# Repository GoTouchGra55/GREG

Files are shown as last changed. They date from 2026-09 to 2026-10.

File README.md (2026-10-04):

# GREG

GREG is a custom SBC designed to act as the main computer for a rover. It is built around the Allwinner T527 SoC and includes custom memory, power management, connectivity, camera, display, sensor, and motor-control hardware.

CAD REPO - [REPO](https://github.com/unknowngamer69/Orion-Rover)

## Hardware

- SoC: Allwinner T527
- RAM: 2 GB Samsung LPDDR4
- PMIC: AXP717-family
- Storage: MicroSD
- Networking: Ethernet
- Connectivity: 2× USB-A + 1× USB-C
- Display: HDMI + 5" LCD interface
- Cameras: 3-camera support (2 with multiplexing)
- Sensors: 6× ToF + LiDAR
- Debug: UART/debug connector
- Expansion: External breakout connector

## Motor Driver

Motor control is handled by a separate PCB instead of the T527.

- MCU: STM32G4
- Motor drivers: 3× DRV8262
- Motors: 6× brushed DC motors with built-in encoders

Separating the motor controller from the SBC keeps the main PCB free from clutter and noise.

## Schematics

SBC - [SEE SCHEMATICS](<Schematics(PDF)/GREG.pdf>)  
Motor Driver - [SEE SCHEMATICS](<Schematics(PDF)/GREG-MTRDRV.pdf>)

## Routing

### Motor Driver

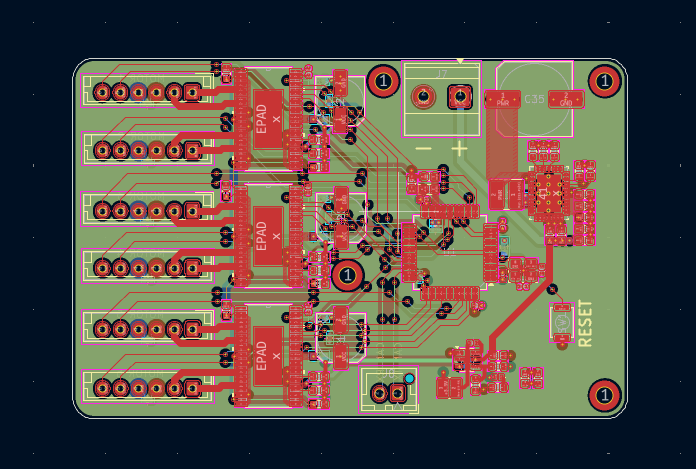
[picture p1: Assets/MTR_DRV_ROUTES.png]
Driver Routes

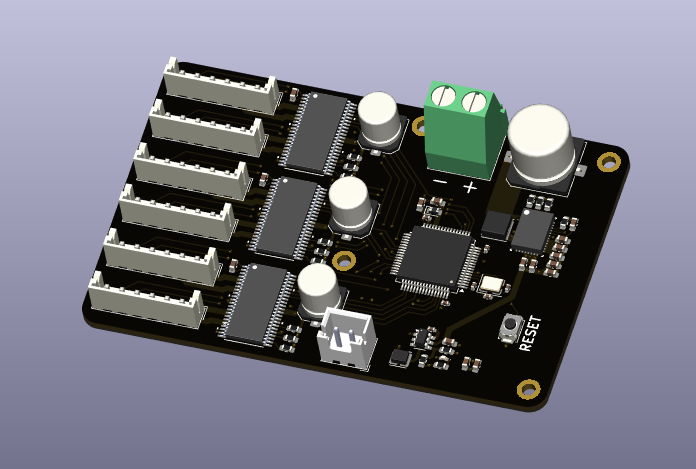
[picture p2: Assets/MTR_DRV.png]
Driver


### SBC (incomplete)

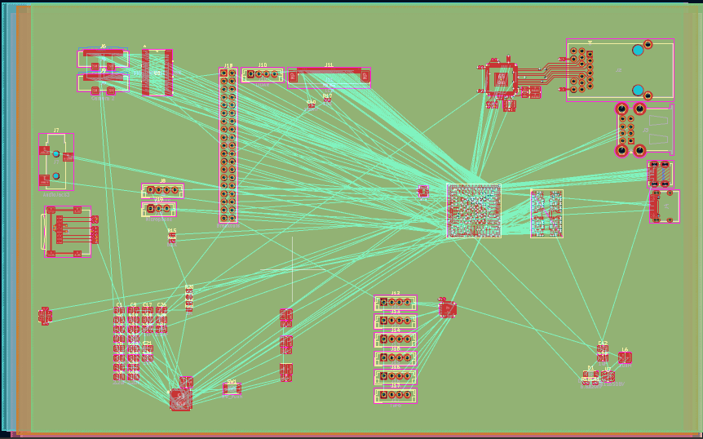
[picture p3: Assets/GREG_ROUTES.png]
GREG SBC


## Authors

Shaurya (Electronics) - [@GoTouchGra55](https://github.com/GoTouchGra55)  
Krish (CAD) - [@unknowngamer69](https://github.com/unknowngamer69)

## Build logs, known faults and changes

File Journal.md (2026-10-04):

# Week 1

## DAY 1

Today, I spent the entire time researching and configuring components on kicad. I did the research part off camera. I was initially planning to use the Rockchip RK3566 processor but it was lacking a proper datasheet so transitioned over to a more open Allwinner T527 processor. This thing has a great documentation and its cheap too!

For the RAM, I was honestly so confused between so many different choices. With the ongoing rammagedon, I though the prices would be crazy but I was shocked on seeing a 16Gb chip for as low as $49 on lcsc. It's cheap, right?

Notice anything? I wrote 16"Gb" and not "GB". This was the entire source of my confusion. Turns out 16Gb is actually just 2GB of ram. So yeah $49 definitely pretty expensive for 2GB of ram ;-;

I decided to go with the SAMSUNG K4F6E3S4HM-THCL. Its a pretty popular chip for embedded systems. Then, started wiring the DDR4 ram. I thought it would be hard af but wiring it up was just connecting similarly named pins from the CPU and on the RAM chip. With that, I finished the task!

https://lapse.hackclub.com/timelapse/3uVjpeV-KdUG

## DAY 2

Today was spent on more wiring. But I wired up the power management ic (PMIC) today. Turns out every different cpu has a whole different PMIC! I thought of using the same PMIC as used in the rk3566 but turns out it was incompatible. So, the compatible chip for the Allwinner T527 processor is the AXP717 PMIC.

Then I wired the PMIC according to the datasheet application. Its still a bit confusing but I think chatgpt or claude and elaborate it for me, if I'm unable to comprehend the datasheet contents. I also wired up power for the processor. It had a lot of different voltage requirements but i guess that's what the PMIC is supposed to be used for instead a billion different voltage regulators.

https://lapse.hackclub.com/timelapse/Uc_4LHCtApbX

## Day 3

Today I added wired connectivity to the board. I added stuff like 1 ethernet, 2 usb-a ports, 1 usb-c port, 2 camera connectors, 1 debug terminal, and 1 hdmi output port. The one that was the most confusing here are the camera connectors. We originally planned for 2 cameras (3 now) and I thought that there were enough pins on the cpu for it, but even using the MIPI DSI from the datasheet, there aren't enough pins for 2 cams. So, I'll need to figure something else out tomorrow for 3 cams.

I literally had to change the camera connector pinout 3 times bc for the first time, I thought we were going for a raspberry pi style camera so I copied that pinout. That was wrong. We changed the camera and I didn't look for the specifics of the camera we'd use. So, I thought copying a standard MIPI camera pinout was a good idea. Not a good idea again. The camera my teammate chose was the most niche camera I've ever seen. Then, I copied the final pinout for that specific camera.

Finally, I also added the micro-sd card memory section. Idk why but I went with stacked USB-A ports like a raspberry pi. Probably because it saves space. I forgot what I was thinking then.

https://lapse.hackclub.com/timelapse/OWU4e0SMXuE3

## Day 4

Today I cleaned up the camera config. Yesterday, I had cheated a bit by only making one camera functional and the other pretty much disabled. So, I added a multiplexer so that I could switch electronically between the two cameras. This was very simple to add as all the pins were pretty much self-explanatory on the MUX.

Then, I added the connectors for all extra devices to be used with the rover. I added connectors for a LiDAR, a 5" LCD display, 6x ToF sensors, and a breakout. For the 5" lcd, I had to use a separate regulator for the backlights and I also had to use another multiplexer for the ToF sensors as using up that many I2C pins would be painful to route and redundant. After that, I cleaned everything up and fixed any erros that I had made.

Finally, I've finished the schemati- SHIT. I forgot the motor driver section. Tomorrow, I'll work on the motor drivers then.

https://lapse.hackclub.com/timelapse/n_8mE_Owrke_

## Day 5

Today, I've planned to make the schematic for the motor driver. Hopefully this doesn't take too long. So, I started off with cubemx. I had to use an stm32g4 series mcu because, I really didn't want this driver to be on the SBC. That would make the sbc way too cluttered and also noisy. So, I setup some pins and timers in cubemx. It was around this time that something crashed on the system and the recording was stopped. So, I just have a random 10min lapse.

https://lapse.hackclub.com/timelapse/YH5z8TwuD9Iz

Then, I opened up kicad and set up the mcu with decoupling capacitors, reset circuitry, crystal, etc. After that, I added a drv8262 motor driver. I used this because it supported two motors instead of just one. That would mean I'd have to use only 3 of these for the 6 planned motors. The first symbol I imported for the driver was very confusing to me, so i replaced it with a "better" version.

Even after that, it took me a lot of time to figure out the pinouts. The board had multiple pins with the same name. I figured out that it was to accomodate for the huge current requirements for the motors. Also, the driver had a different pinout for single and dual motor modes. I had added some incorrect configs in cubemx, so retraced my steps and reconfigured the project. Next, it was pretty much smooth sailing. I added the power circuitry from an old project as it had a pretty similar power i/o requirement. I eventually added the CAN to both the stm32 and the t527.

Then, I changed the 2x18 pin connector to a 2x19 pin version to include the two CAN pins. Finally, I assigned the footprints to both the driver and the driver. I realized that a couple of the footprints were missing models, so i manually assigned models to those. With that, I concluded the schematics for the SBC + Motor Driver. I'll be routing the pcbs in the following week!

https://lapse.hackclub.com/timelapse/VLZOeNz0L1pe

# Week 2

# Day 1

Firstly, I added M2 mounting holes and also fixed some footprint issues for the motor driver. After that, I did some decoupling capacitor placement for the mcu. I also routed the localized sections together and used copper pours for the parts expecting high currents. That's basically all of what I've done today.

https://lapse.hackclub.com/timelapse/X0dPpF9x8SwO

# Day 2

Today, I planned out the placements for the motor drivers. It was tedious due to the oddly long nature of the motor connectors. I put them vertically on each other as horizontal would take too much space. This looks pretty good tbh. After that, I placed remaining motor driver components like the decoupling caps, resistors, bulk capacitor, etc. Then, I connected some of the localized components together with the whole board.

https://lapse.hackclub.com/timelapse/TpOebbLc9Wzu

# Day 3

Today, I connected the motor drivers to the mcu itself. Previously, it was only routed locally. After that, I cleaned up some of the older routes. I also figured out that I had accidentally mixed up the internal power supply to the external through a silly error. So, I fixed that and also fixed the corresponding routes.

https://lapse.hackclub.com/timelapse/athXvKkx-Ld6

# Day 4

Today, I connected the motor encoders to the mcu. This also resulted in some revised routes. After that, I had to resolving some plane issues. Then, I moved over a few sections to make the board more compact as it was just way too big and scattered. The motor driver is now complete.

https://lapse.hackclub.com/timelapse/TlkEq0aHov0p

# Day 5

Today, I started work on routing the sbc itself. This was very confusing as I've never worked with an sbc before. I tried to use vias but they didnt really want to work. So, I found out that I was supposed to use micro vias. I also tried to connect long distance traces together but later changed my mind as I don't think that it's a good idea. I'd rather keep the traces short and tidy instead of long and weird. Then, I followed a similar concept in the ram. I only routed together the grouped components. Gonna do more work tomorrow.

https://lapse.hackclub.com/timelapse/h11k2Ic1V0Ab

# Day 6

Today, I wired up some local routes in the sbc. I wanted to start with the RAM but as a beginner to custom sbc designs, shits pretty intimidating yk. So, I routed the ethernet section first. Then, I routed up some crystals and finally the SD card memory section. I wanted to keep the labels at first so I spent some time "prettyfying" the component placements, but then later changed my mind as it took too fricking long to do and imo just looked trash.

https://lapse.hackclub.com/timelapse/Ca1tS8nBZieB

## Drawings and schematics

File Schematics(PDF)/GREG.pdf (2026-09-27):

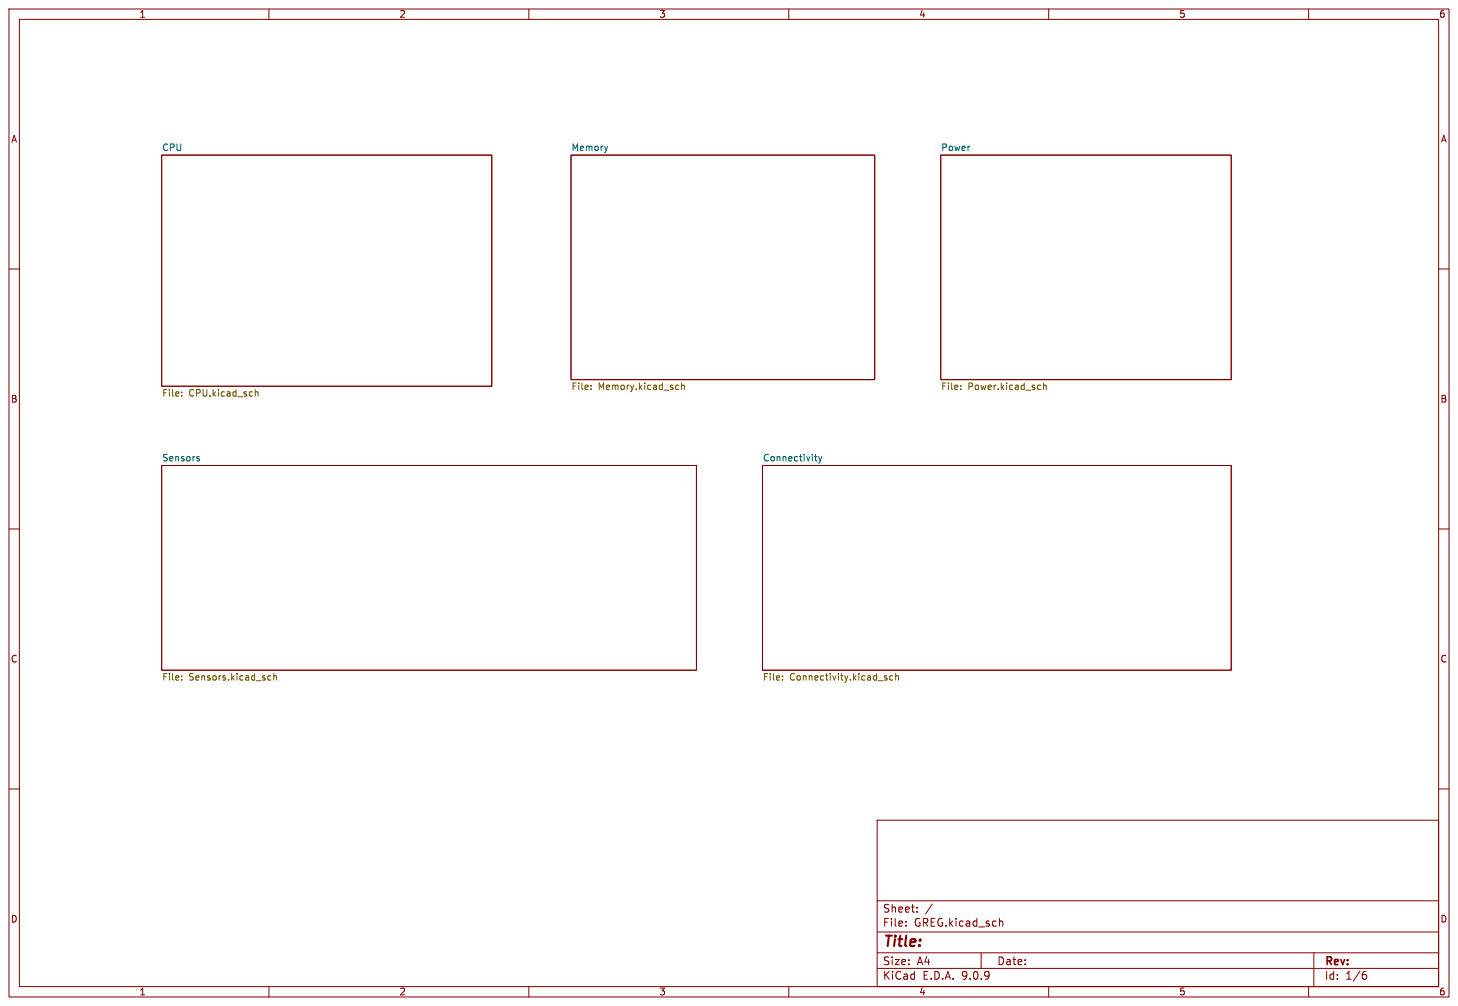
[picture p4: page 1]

Memory File: Memory.kicad_sch CPU

Id: 1/6 Title: File: GREG.kicad_sch Sheet: /

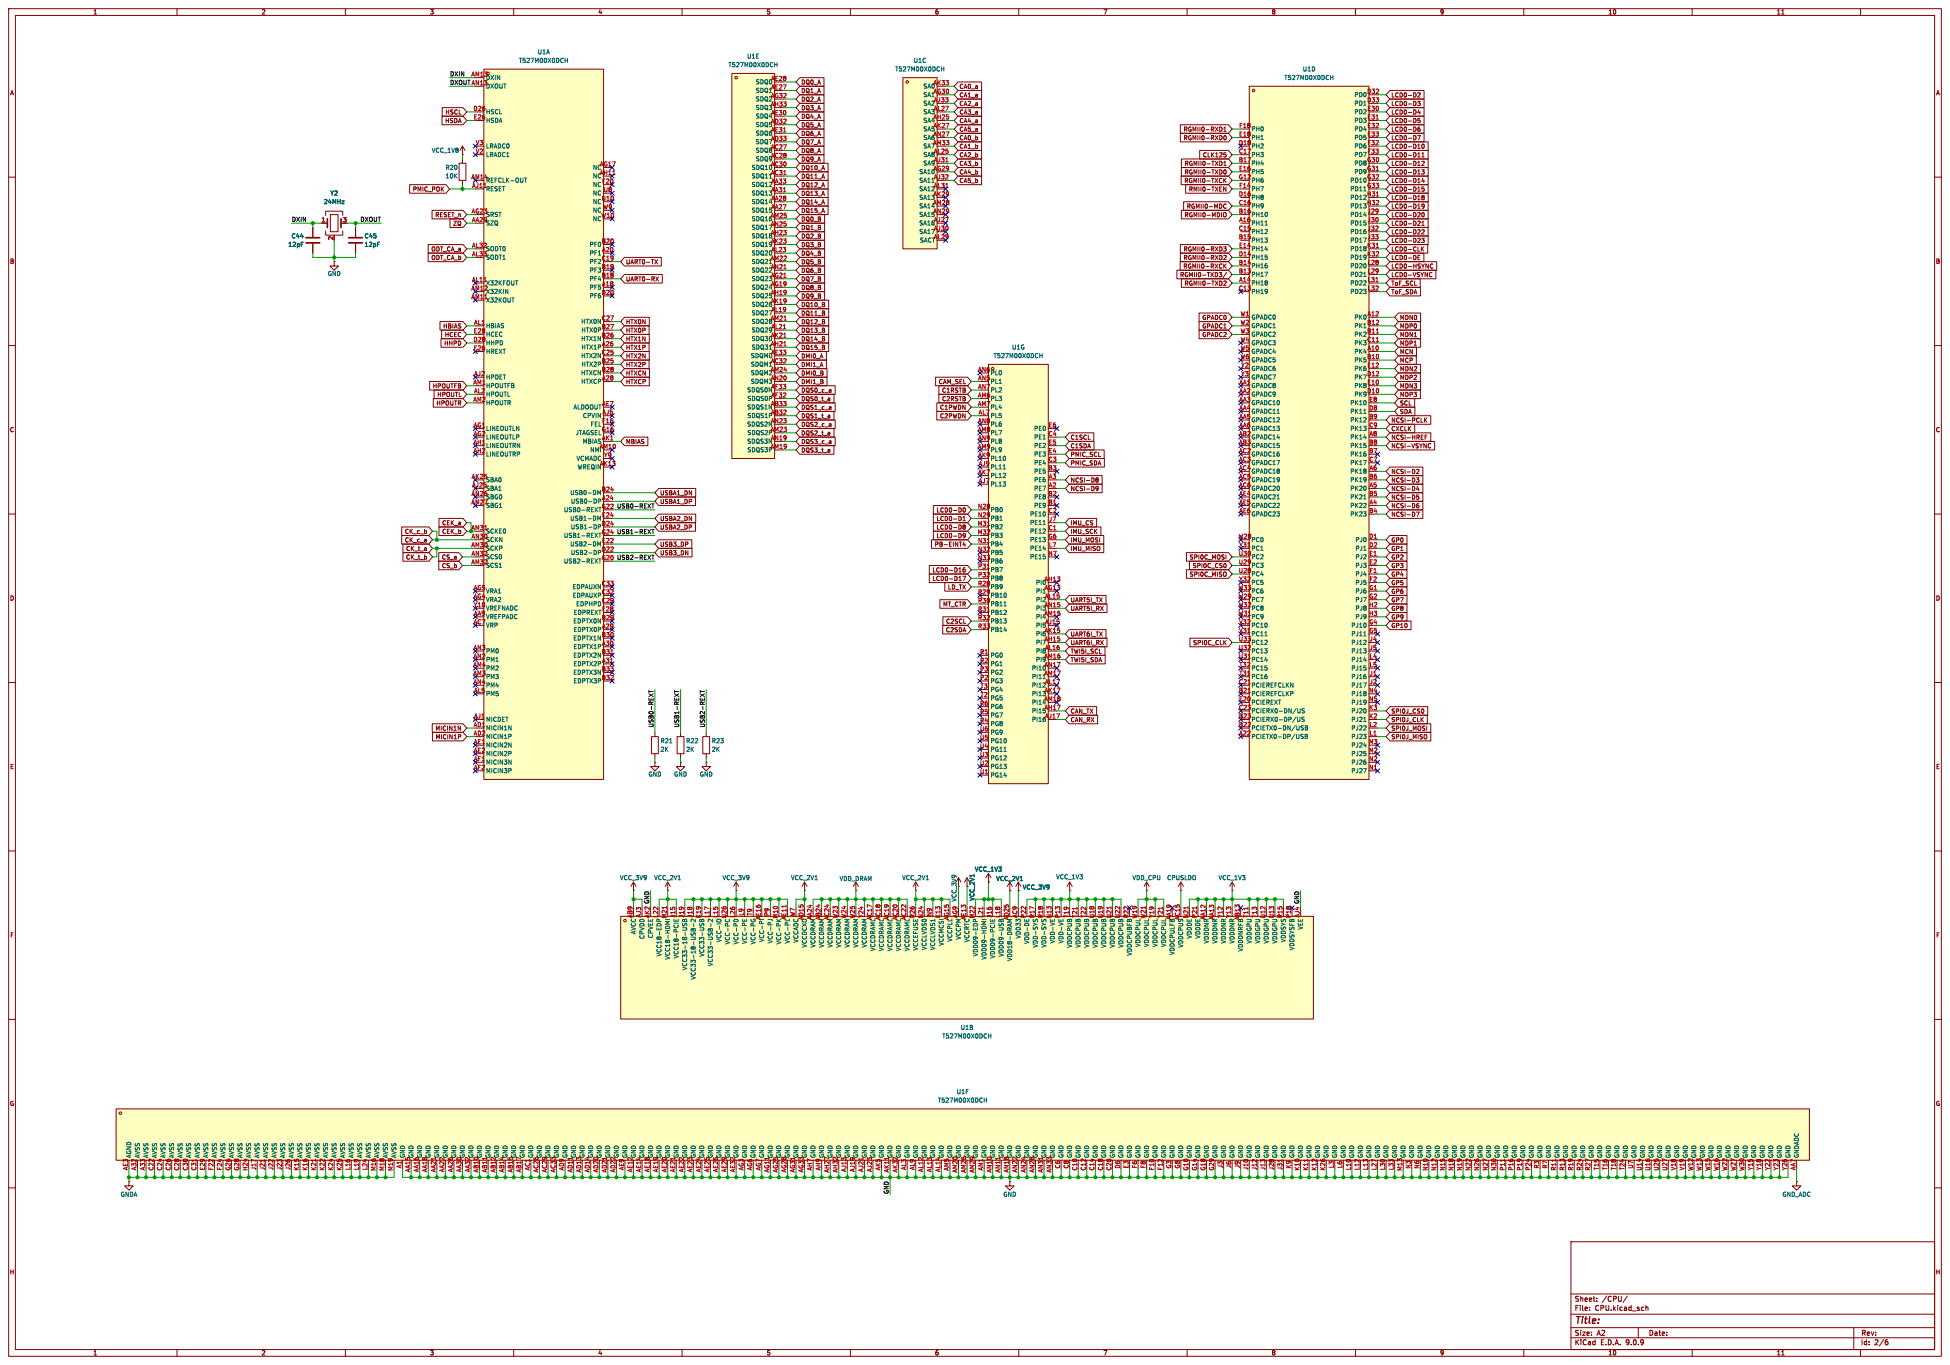
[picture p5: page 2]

T527M00X0DCH
LRADC1 V2 REFCLK-OUT AM14RESET AJ11SRST AG23SZQ AA29SODT0 AL32SODT1 AL33X32KFOUT AL11X32KIN AM12X32KOUT AM11HBIAS AL1 HCEC E28 HHPD D28 HREXT F26 HPDET AJ2 HPOUTFB AM1HPOUTL AL2 HPOUTR AM2
NCAG17 NCAH11 NCF20 NC U8 NCU10 NC W9 NCW10 PF0 B20 PF1 A20 PF2 C19 PF3 B19 PF4 B18 PF5 A18 PF6 D20 HTX0N C27 HTX0P B27 HTX1N B26 HTX1P A26 HTX2N C25 HTX2P B25 HTXCNB28 HTXCPA28 ALDOOUTAE7 CPVIN AJ5 FELF16

HCEC
JTAGSELG16 MBIASAK1 NMIAM10 VCMADC Y9 WREQINAK13 USB0-DM B24 USB0-DP A24 USB0-REXT G22 USB1-DM E24 USB1-DP D24 USB1-REXT G24 USB2-DM E22 USB2-DP D22 USB2-REXT G20 EDPAUXNC33 EDPAUXPC32 EDPHPDC29 EDPREXTF28 EDPTX0N B29 EDPTX0P A29 EDPTX1N B30 EDPTX1P A30 EDPTX2N B31 EDPTX2P A31 EDPTX3N B33 EDPTX3P B32
LINEOUTRP AH2SBA0 AK25SBA1 AJ25SBG0 AN26SBG1 AM27SCKE0 AM31SCKN AN30SCKP AM30SCS0 AN32SCS1 AM32VRA1 AG5VRA2 AG4VREFNADC Y10 VREFPADC AA9VRP AC7PM0 AN3PM1 AN2PM2 AM4PM3 AM3PM4 AN4PM5 AL5 MICDET AJ1 MICIN1N AD1MICIN1P AD2MICIN2N AE1 MICIN2P AE2 MICIN3N AF1 MICIN3P AF2

C21 PCIEREFCLKP
B21 PCIEREXT E20 PCIERX0-DN/US C23 PCIERX0-DP/US

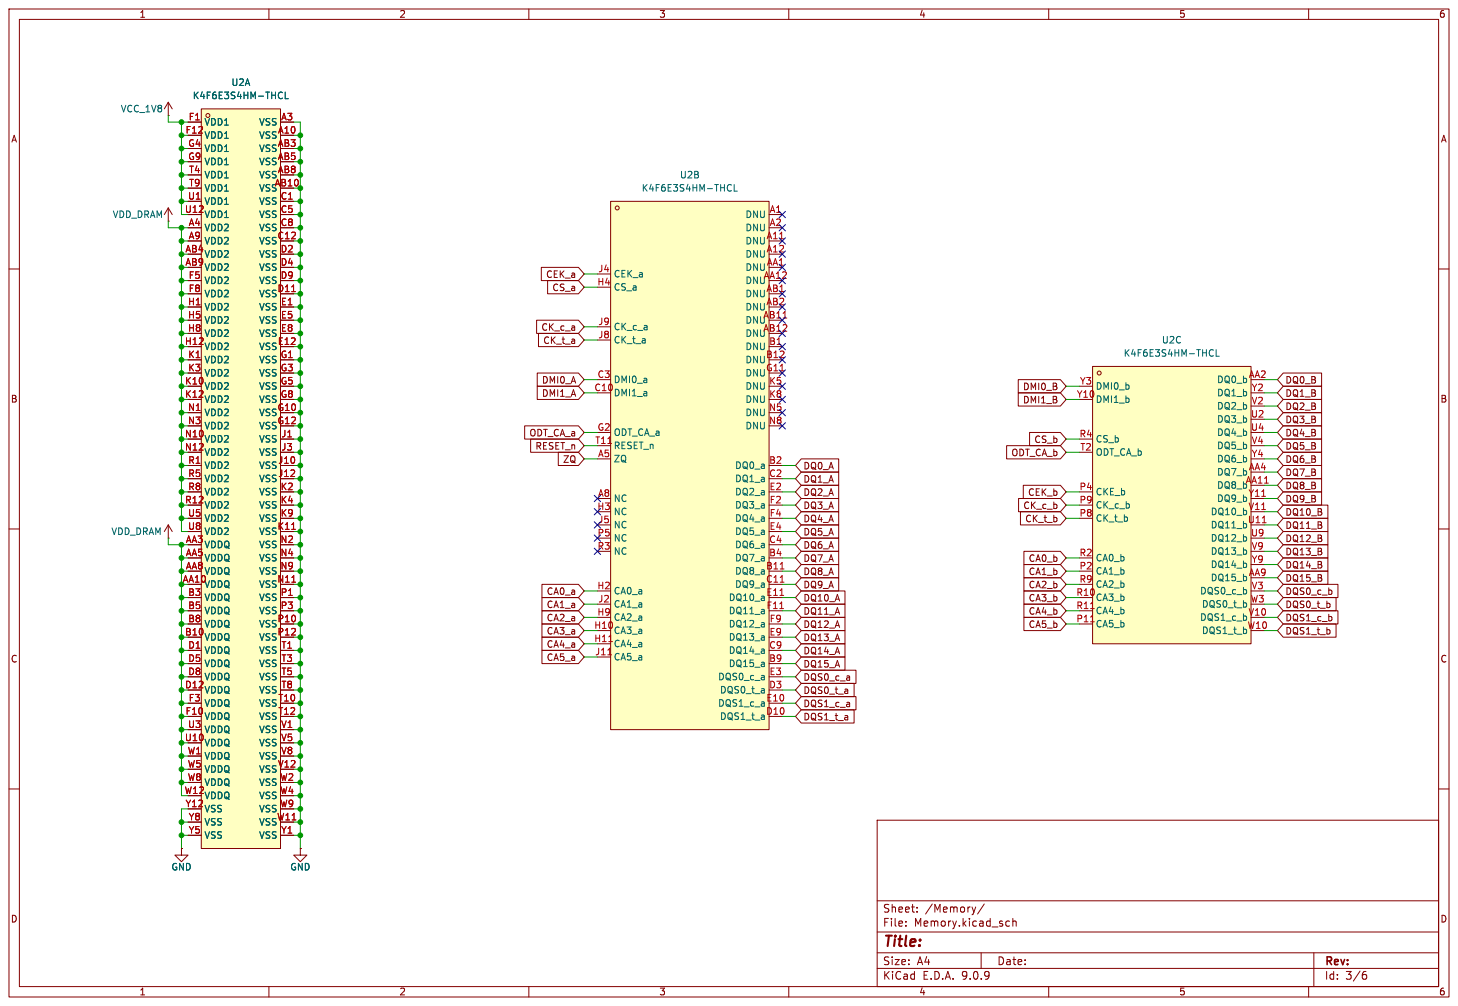
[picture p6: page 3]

Id: 3/6 Title: File: Memory.kicad_sch Sheet: /Memory/

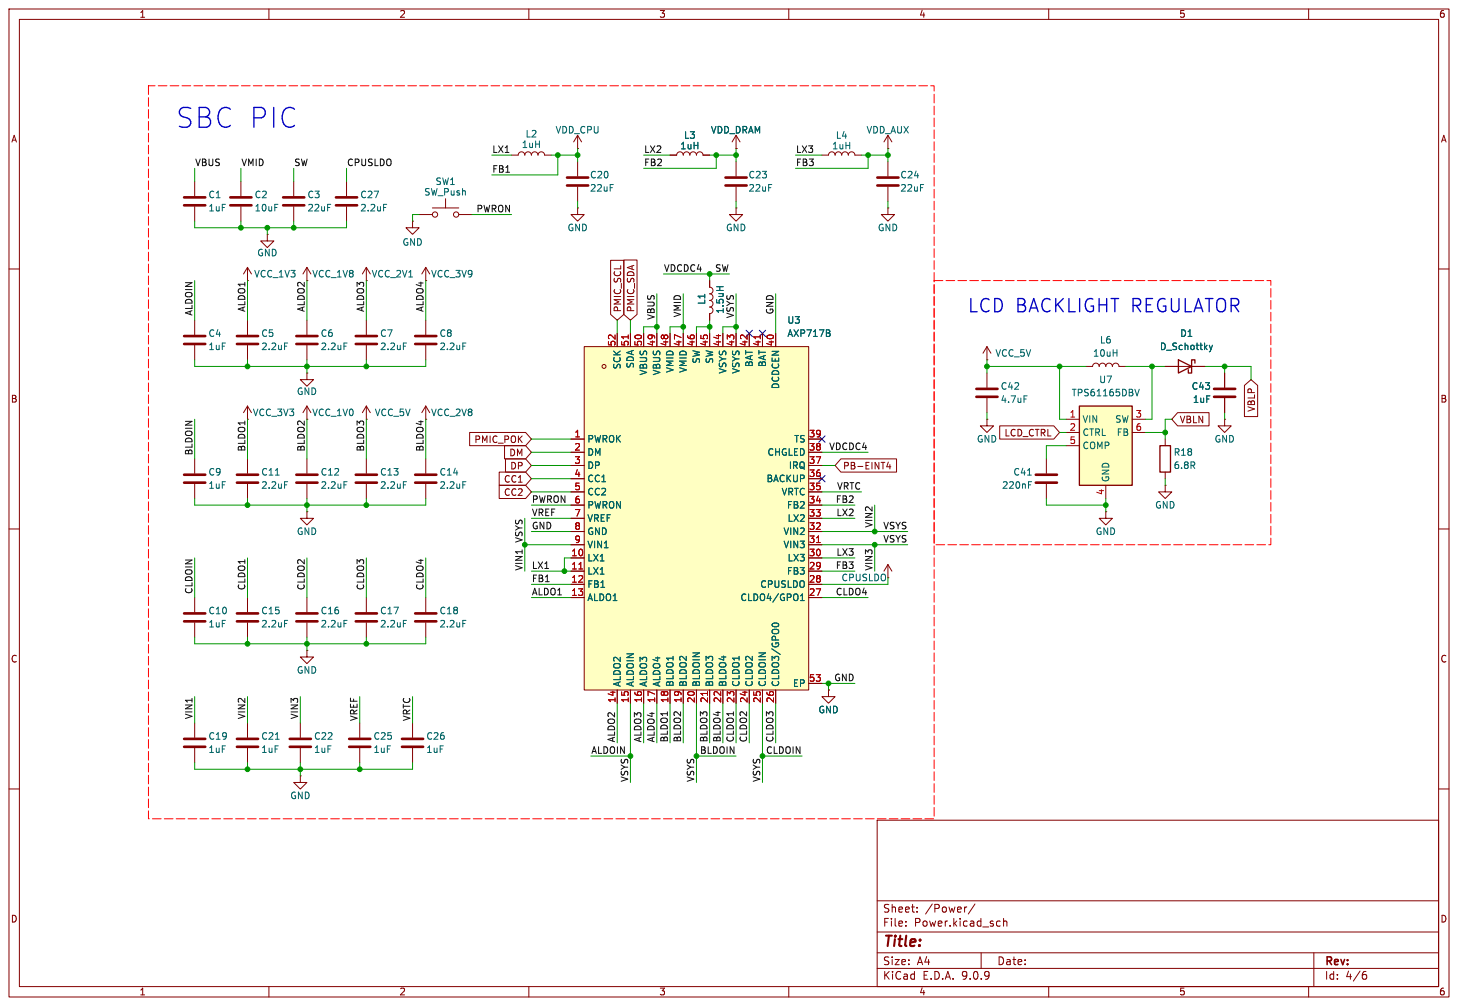
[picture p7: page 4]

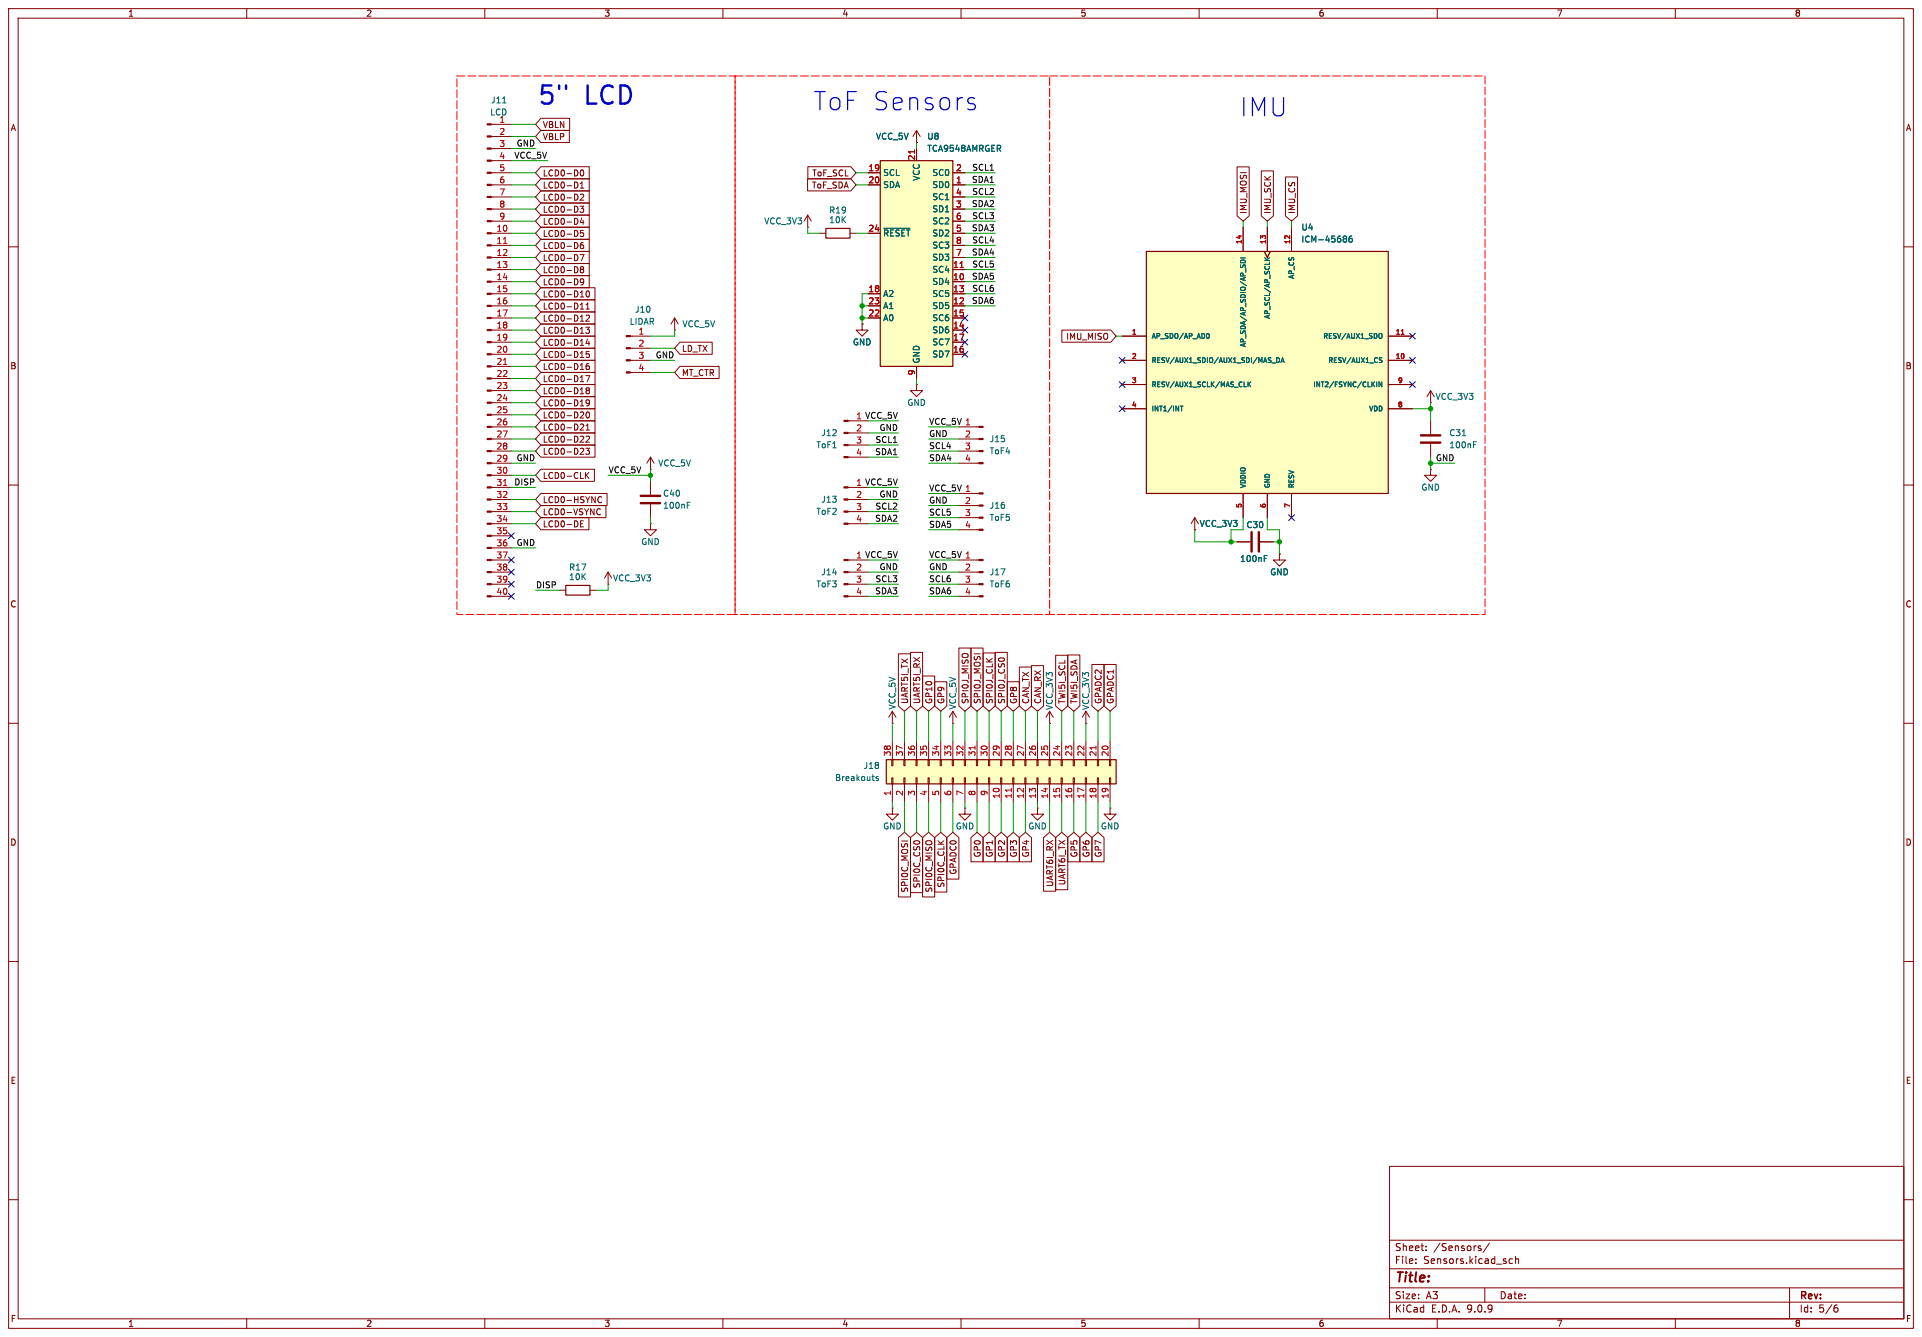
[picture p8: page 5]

Id: 5/6 Title: File: Sensors.kicad_sch Sheet: /Sensors/

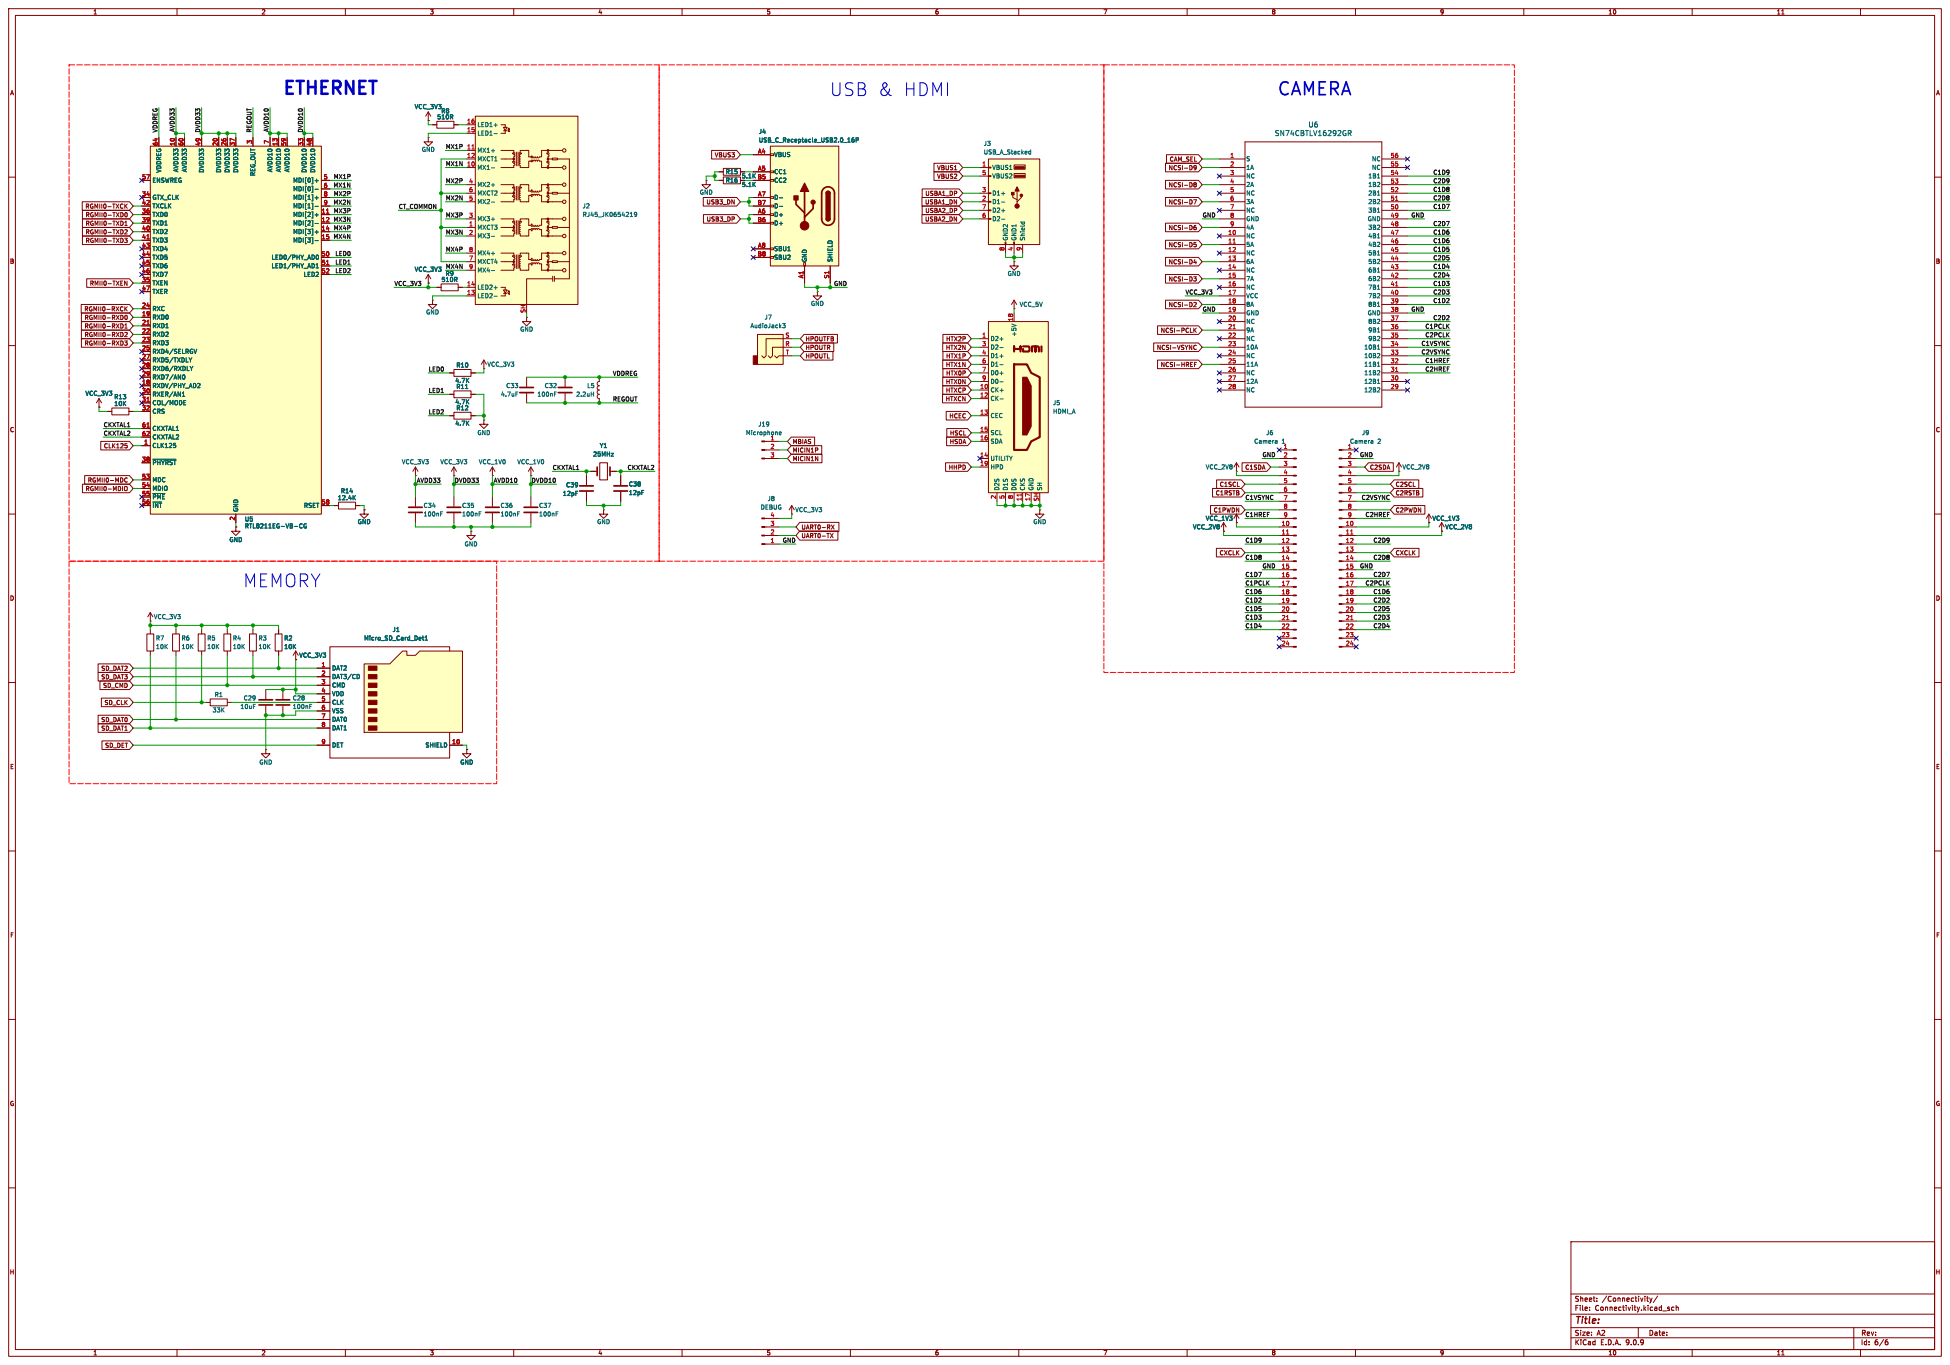
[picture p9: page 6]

8 CKS 11 GND 17 SH SH

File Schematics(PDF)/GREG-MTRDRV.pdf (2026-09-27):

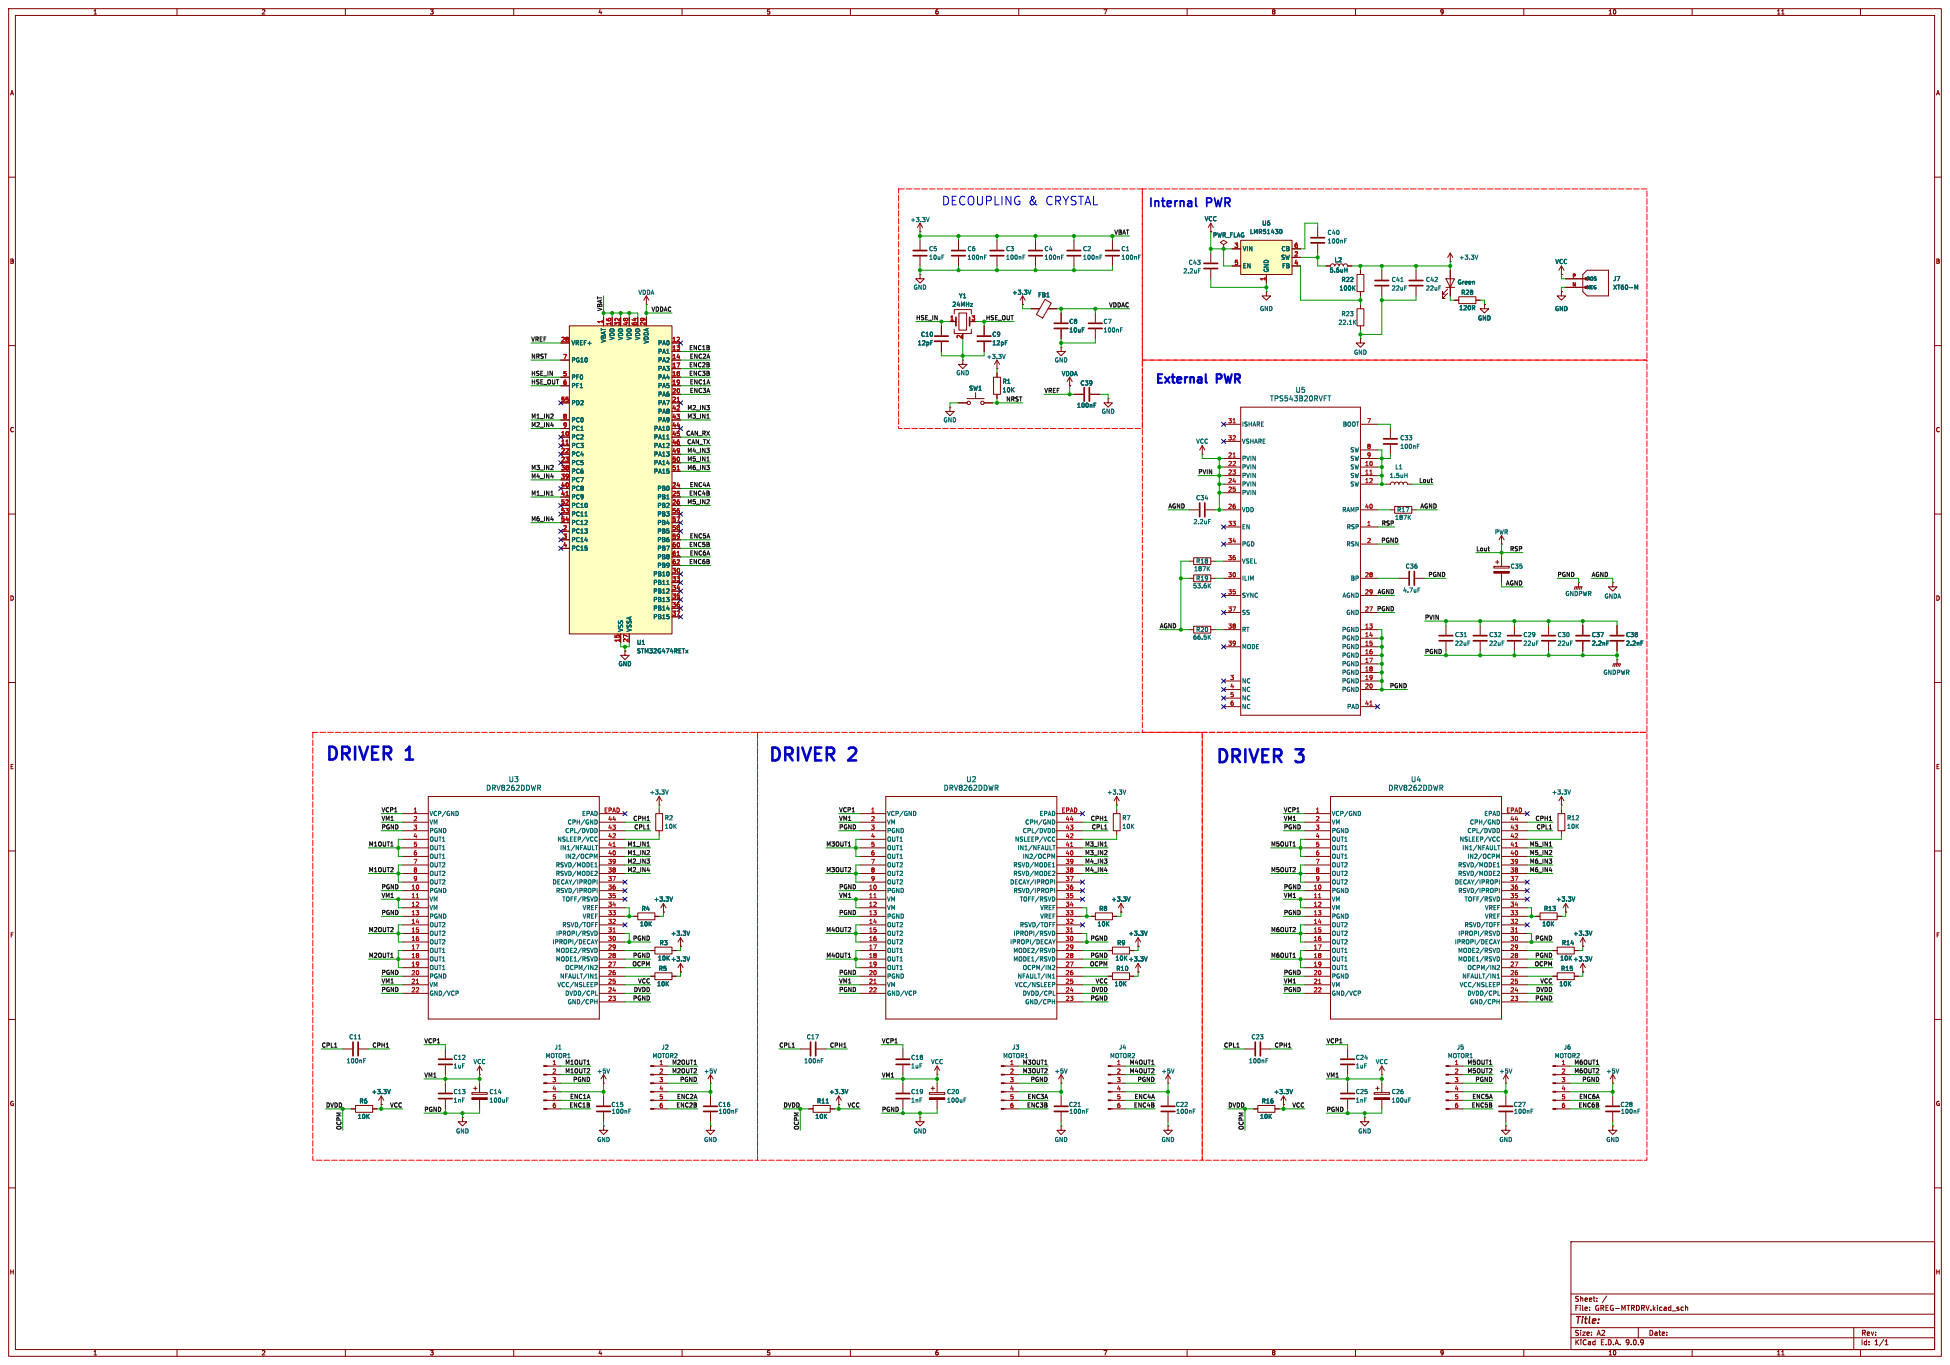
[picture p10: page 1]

1 VDD 16 VDD 32 VSS 15 VDD 48 VSSA 27 VDD 64 VDDA 29 PA0 12 PA1 13 PA2 14 PA3 17 PA4 18 PA5 19 PA6 20 PA7 21 PA8 42 PA9 43 PA10 44 PA11 45 PA12 46 PA13 49 PA14 50 PA15 51 PB0 24 PB1 25 PB2 26 PB3 56 PB4 57 PB5 58 PB6 59 PB7 60 PB8 61 PB9 62 PB10 30 PB11 33 PB12 34 PB13 35 PB14 36 PB15 37 U1STM32G474RETx

1 VDD 16 VDD 32 VSS 15 VDD 48 VSSA 27 VDD 64 VDDA 29 PA0 12 PA1 13 PA2 14 PA3 17 PA4 18 PA5 19 PA6 20 PA7 21 PA8 42 PA9 43 PA10 44 PA11 45 PA12 46 PA13 49 PA14 50 PA15 51 PB0 24 PB1 25 PB2 26 PB3 56 PB4 57 PB5 58 PB6 59 PB7 60 PB8 61 PB9 62 PB10 30 PB11 33 PB12 34 PB13 35 PB14 36 PB15 37 R1 SW1 10K

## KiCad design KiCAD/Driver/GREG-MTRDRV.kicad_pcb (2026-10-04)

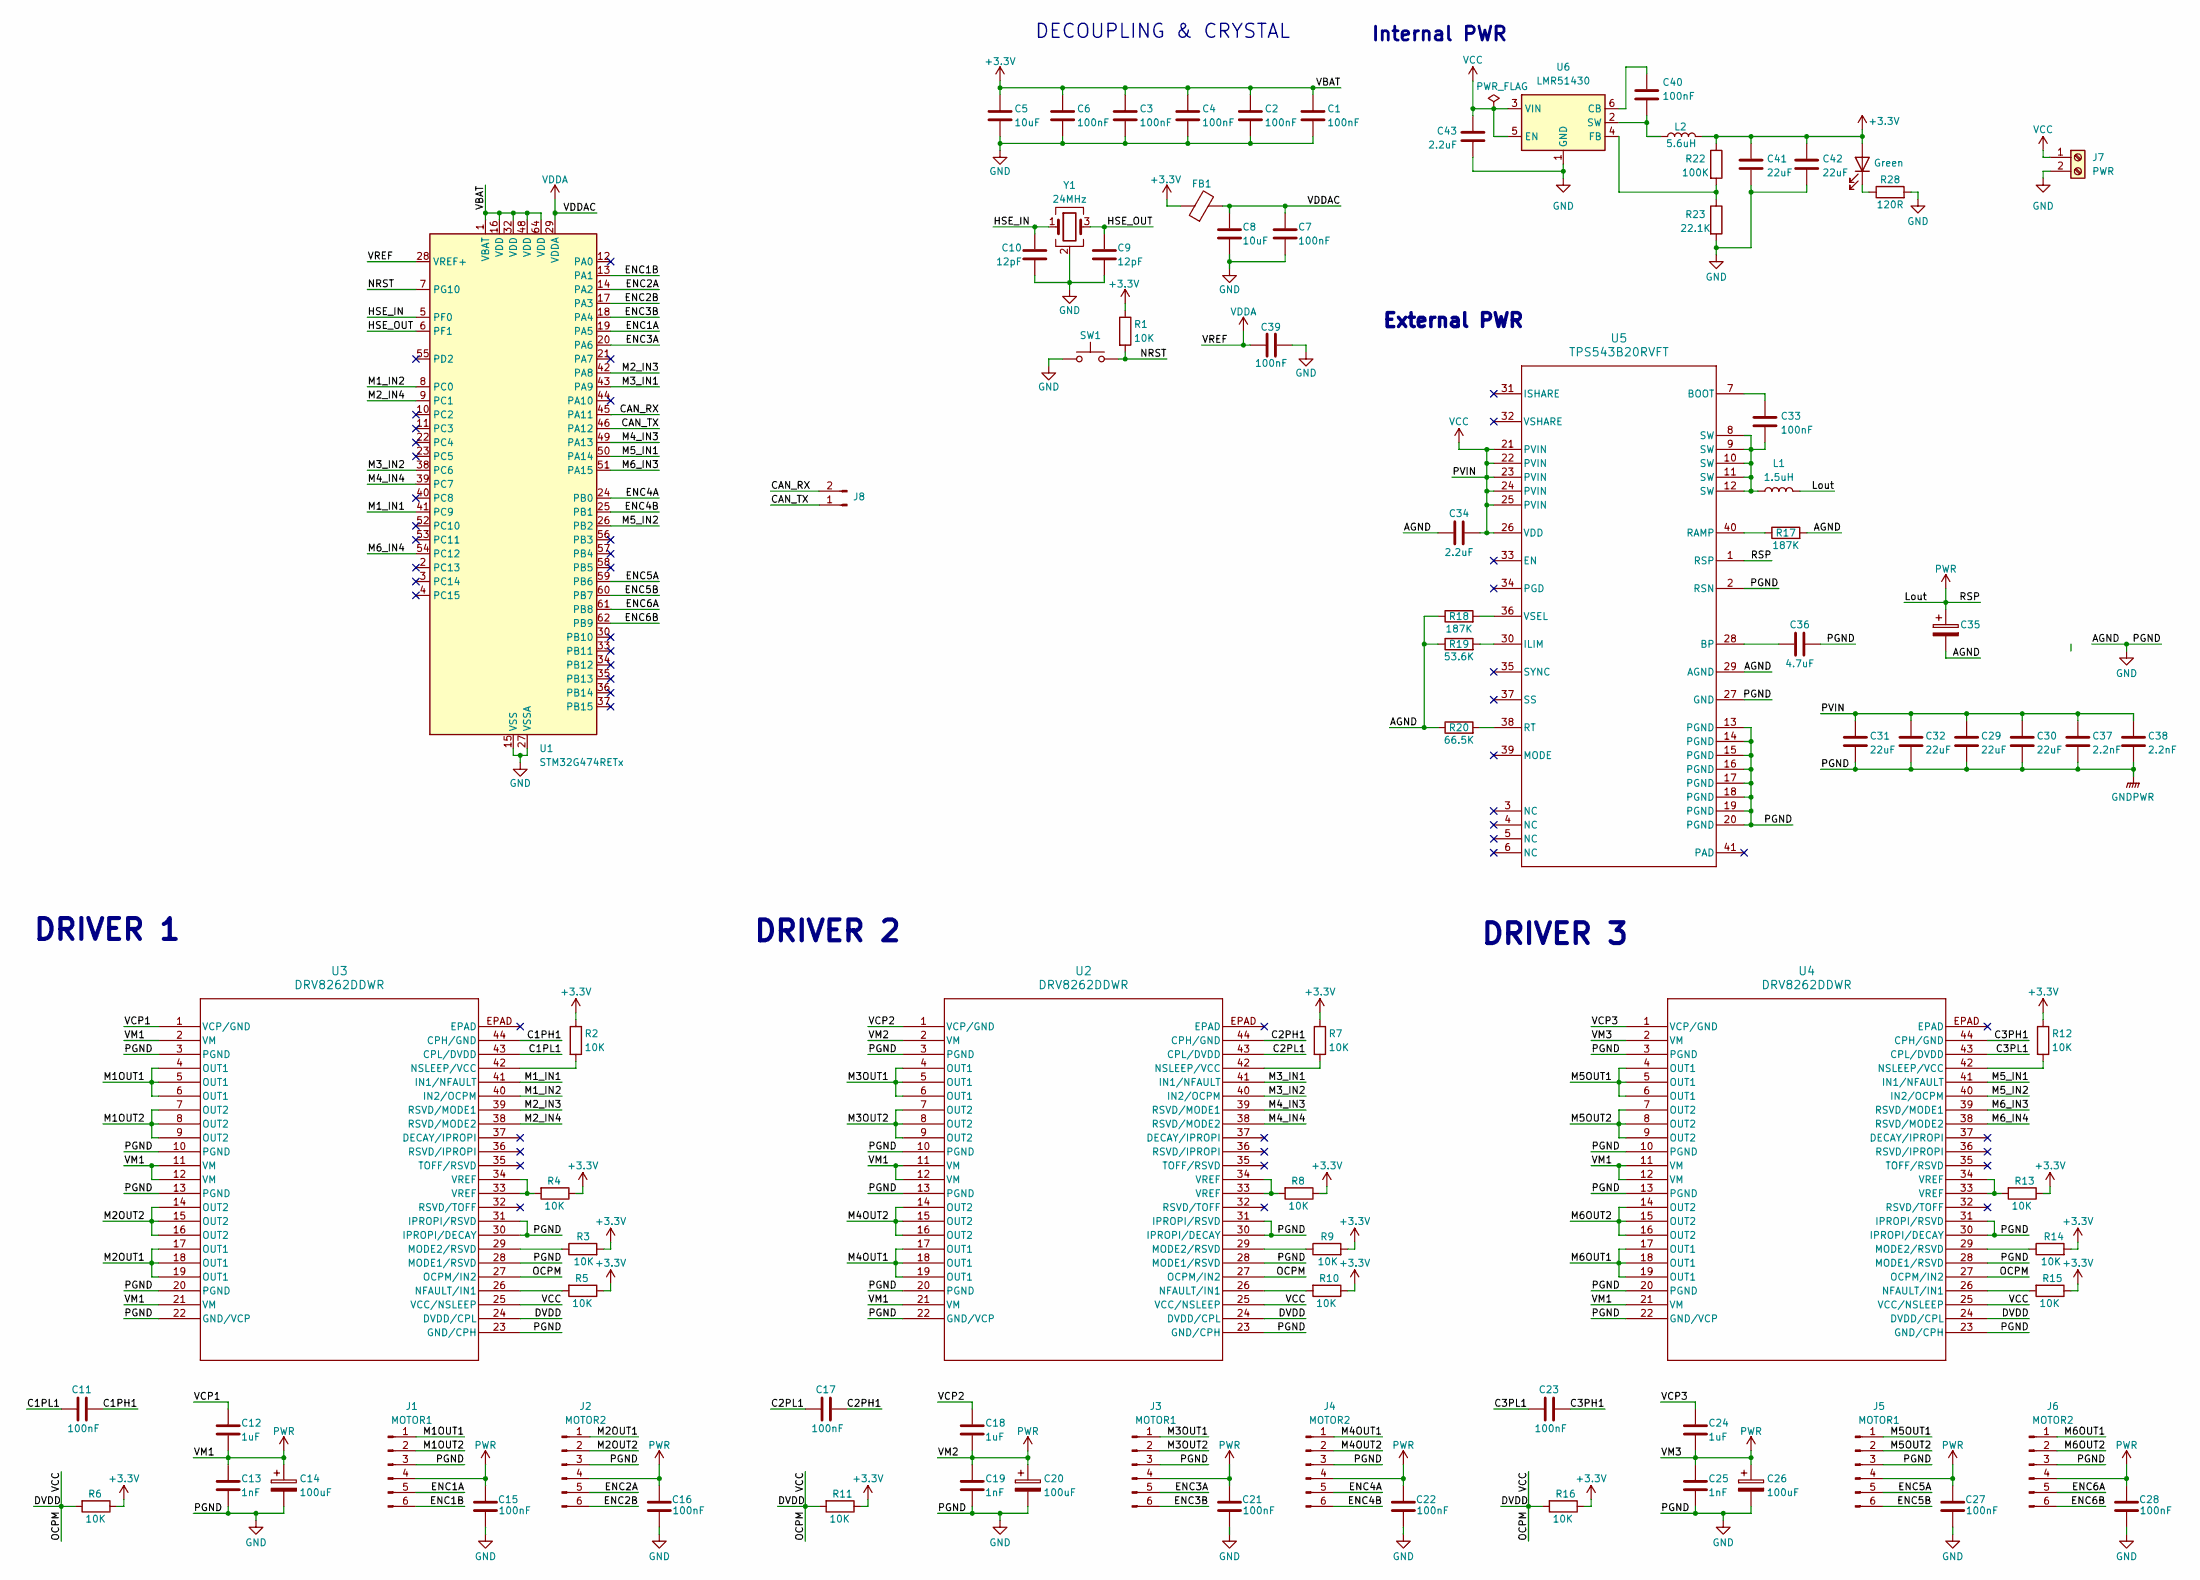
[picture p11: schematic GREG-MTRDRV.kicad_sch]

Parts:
C1, C2, C3, C4, C6, C7, C11, C15, C16, C17, C21, C22, C23, C27, C28, C33, C39, C40: 100nF; C_0402_1005Metric
C5, C8: 10uF; C_0603_1608Metric
C9, C10: 12pF; C_0402_1005Metric
C12, C18, C24: 1uF; C_0603_1608Metric
C13, C19, C25: 1nF; C_0402_1005Metric
C14, C20, C26: 100uF; C_Elec_6.3x7.7
C29, C30, C31, C32, C41, C42: 22uF; C_0603_1608Metric
C34, C43: 2.2uF; C_0603_1608Metric
C35: 1000uF; C_Elec_10x10.2
C36: 4.7uF; C_0603_1608Metric
C37, C38: 2.2nF; C_0603_1608Metric
FB1: FerriteBead; D_0603_1608Metric
Int_Indicator1: Green; LED_0402_1005Metric
J1, J3, J5: MOTOR1; JST_EH_B6B-EH-A_1x06_P2.50mm_Vertical
J2, J4, J6: MOTOR2; JST_EH_B6B-EH-A_1x06_P2.50mm_Vertical
J7: PWR; TerminalBlock_Phoenix_MKDS-1,5-2-5.08_1x02_P5.08mm_Horizont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
J8: Conn_01x02_Pin; JST_XH_B2B-XH-AM_1x02_P2.50mm_Vertical
L1: 1.5uH; L_Cenker_CKCS4018
L2: 5.6uH; L_Cenker_CKCS252010
R1, R2, R3, R4, R5, R6, R7, R8, R9, R10, R11, R12, R13, R14, R15, R16: 10K; R_0603_1608Metric
R17, R18: 187K; R_0603_1608Metric
R19: 53.6K; R_0603_1608Metric
R20: 66.5K; R_0603_1608Metric
R22: 100K; R_0603_1608Metric
R23: 22.1K; R_0603_1608Metric
R28: 120R; R_0603_1608Metric
SW1: SW_Push; SW_Push_SPST_NO_Alps_SKRK
U1: STM32G474RETx; LQFP-64_10x10mm_P0.5mm
U2, U3, U4: DRV8262DDWR; HTSSOP44-DDW_TEX
U5: TPS543B20RVFT; RVF0040A
U6: LMR51430; SOT-23-6
Y1: 24MHz; Crystal_SMD_3225-4Pin_3.2x2.5mm

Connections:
+3.3V: C1.1, C2.1, C3.1, C4.1, C5.1, C6.1, C41.1, C42.1, FB1.1, Int_Indicator1.2 (A), L2.1, R1.1, R2.1, R3.2, R4.1, R5.1, R6.1, R7.1, R8.1, R9.2, R10.1, R11.1, R12.1, R13.1, R14.2, R15.1, R16.1, R22.1, U1.1 (VBAT), U1.16 (VDD), U1.32 (VDD), U1.48 (VDD), U1.64 (VDD)
/C1PH1: C11.2, U3.44 (CPH/GND)
/C1PL1: C11.1, U3.43 (CPL/DVDD)
/C2PH1: C17.2, U2.44 (CPH/GND)
/C2PL1: C17.1, U2.43 (CPL/DVDD)
/C3PH1: C23.2, U4.44 (CPH/GND)
/C3PL1: C23.1, U4.43 (CPL/DVDD)
/CAN_RX: J8.2, U1.45 (PA11)
/CAN_TX: J8.1, U1.46 (PA12)
/ENC1A: J1.5, U1.19 (PA5)
/ENC1B: J1.6, U1.13 (PA1)
/ENC2A: J2.5, U1.14 (PA2)
/ENC2B: J2.6, U1.17 (PA3)
/ENC3A: J3.5, U1.20 (PA6)
/ENC3B: J3.6, U1.18 (PA4)
/ENC4A: J4.5, U1.24 (PB0)
/ENC4B: J4.6, U1.25 (PB1)
/ENC5A: J5.5, U1.59 (PB6)
/ENC5B: J5.6, U1.60 (PB7)
/ENC6A: J6.5, U1.61 (PB8)
/ENC6B: J6.6, U1.62 (PB9)
/HSE_IN: C10.1, U1.5 (PF0), Y1.1
/HSE_OUT: C9.1, U1.6 (PF1), Y1.3
/M1OUT1: J1.1, U3.4 (OUT1), U3.5 (OUT1), U3.6 (OUT1)
/M1OUT2: J1.2, U3.7 (OUT2), U3.8 (OUT2), U3.9 (OUT2)
/M1_IN1: U1.41 (PC9), U3.41 (IN1/NFAULT)
/M1_IN2: U1.8 (PC0), U3.40 (IN2/OCPM)
/M2OUT1: J2.1, U3.17 (OUT1), U3.18 (OUT1), U3.19 (OUT1)
/M2OUT2: J2.2, U3.14 (OUT2), U3.15 (OUT2), U3.16 (OUT2)
/M2_IN3: U1.42 (PA8), U3.39 (RSVD/MODE1)
/M2_IN4: U1.9 (PC1), U3.38 (RSVD/MODE2)
/M3OUT1: J3.1, U2.4 (OUT1), U2.5 (OUT1), U2.6 (OUT1)
/M3OUT2: J3.2, U2.7 (OUT2), U2.8 (OUT2), U2.9 (OUT2)
/M3_IN1: U1.43 (PA9), U2.41 (IN1/NFAULT)
/M3_IN2: U1.38 (PC6), U2.40 (IN2/OCPM)
/M4OUT1: J4.1, U2.17 (OUT1), U2.18 (OUT1), U2.19 (OUT1)
/M4OUT2: J4.2, U2.14 (OUT2), U2.15 (OUT2), U2.16 (OUT2)
/M4_IN3: U1.49 (PA13), U2.39 (RSVD/MODE1)
/M4_IN4: U1.39 (PC7), U2.38 (RSVD/MODE2)
/M5OUT1: J5.1, U4.4 (OUT1), U4.5 (OUT1), U4.6 (OUT1)
/M5OUT2: J5.2, U4.7 (OUT2), U4.8 (OUT2), U4.9 (OUT2)
/M5_IN1: U1.50 (PA14), U4.41 (IN1/NFAULT)
/M5_IN2: U1.26 (PB2), U4.40 (IN2/OCPM)
/M6OUT1: J6.1, U4.17 (OUT1), U4.18 (OUT1), U4.19 (OUT1)
/M6OUT2: J6.2, U4.14 (OUT2), U4.15 (OUT2), U4.16 (OUT2)
/M6_IN3: U1.51 (PA15), U4.39 (RSVD/MODE1)
/M6_IN4: U1.54 (PC12), U4.38 (RSVD/MODE2)
/NRST: R1.2, SW1.2, U1.7 (PG10)
/VCP1: C12.1, U3.1 (VCP/GND)
/VCP2: C18.1, U2.1 (VCP/GND)
/VCP3: C24.1, U4.1 (VCP/GND)
GND: C1.2, C2.2, C3.2, C4.2, C5.2, C6.2, C7.2, C8.2, C9.2, C10.2, C13.2, C14.2, C15.2, C16.2, C19.2, C20.2, C21.2, C22.2, C25.2, C26.2, C27.2, C28.2, C29.2, C30.2, C31.2, C32.2, C34.1, C35.2, C36.2, C37.2, C38.2, C39.1, C41.2, C42.2, C43.2, J1.3, J2.3, J3.3, J4.3, J5.3, J6.3, J7.2, R17.2, R18.1, R19.1, R20.1, R23.2, R28.2, SW1.1, U1.15 (VSS), U1.27 (VSSA), U1.31 (VSS), U1.47 (VSS), U1.63 (VSS), U2.3 (PGND), U2.10 (PGND), U2.13 (PGND), U2.20 (PGND), U2.22 (GND/VCP), U2.23 (GND/CPH), U2.28 (MODE1/RSVD), U2.30 (IPROPI/DECAY), U2.31 (IPROPI/RSVD), U3.3 (PGND), U3.10 (PGND), U3.13 (PGND), U3.20 (PGND), U3.22 (GND/VCP), U3.23 (GND/CPH), U3.28 (MODE1/RSVD), U3.30 (IPROPI/DECAY), U3.31 (IPROPI/RSVD), U4.3 (PGND), U4.10 (PGND), U4.13 (PGND), U4.20 (PGND), U4.22 (GND/VCP), U4.23 (GND/CPH), U4.28 (MODE1/RSVD), U4.30 (IPROPI/DECAY), U4.31 (IPROPI/RSVD), U5.2 (RSN), U5.13 (PGND), U5.14 (PGND), U5.15 (PGND), U5.16 (PGND), U5.17 (PGND), U5.18 (PGND), U5.19 (PGND), U5.20 (PGND), U5.27 (GND), U5.29 (AGND), U6.1 (GND), Y1.2 (G), Y1.4 (G)
unnamed: C33.2, L1.1, U5.8 (SW), U5.9 (SW), U5.10 (SW), U5.11 (SW), U5.12 (SW)
unnamed: Int_Indicator1.1 (K), R28.1
unnamed: R4.2, U3.33 (VREF), U3.34 (VREF)
unnamed: R8.2, U2.33 (VREF), U2.34 (VREF)
unnamed: R13.2, U4.33 (VREF), U4.34 (VREF)
unnamed: R9.1, U2.29 (MODE2/RSVD)
unnamed: R10.2, U2.26 (NFAULT/IN1)
unnamed: R7.2, U2.42 (NSLEEP/VCC)
unnamed: R3.1, U3.29 (MODE2/RSVD)
unnamed: R5.2, U3.26 (NFAULT/IN1)
unnamed: R2.2, U3.42 (NSLEEP/VCC)
unnamed: R14.1, U4.29 (MODE2/RSVD)
unnamed: R15.2, U4.26 (NFAULT/IN1)
unnamed: R12.2, U4.42 (NSLEEP/VCC)
unnamed: C33.1, U5.7 (BOOT)
unnamed: C36.1, U5.28 (BP)
unnamed: R19.2, U5.30 (ILIM)
unnamed: R17.1, U5.40 (RAMP)
unnamed: R20.2, U5.38 (RT)
unnamed: R18.2, U5.36 (VSEL)
unnamed: C40.1, U6.6 (CB)
unnamed: R22.2, R23.1, U6.4 (FB)
unnamed: C40.2, L2.2, U6.2 (SW)
VDDA: C7.1, C8.1, C39.2, FB1.2, U1.28 (VREF+), U1.29 (VDDA)

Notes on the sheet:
DECOUPLING & CRYSTAL
DRIVER 3
DRIVER 1
DRIVER 2
External PWR
Internal PWR

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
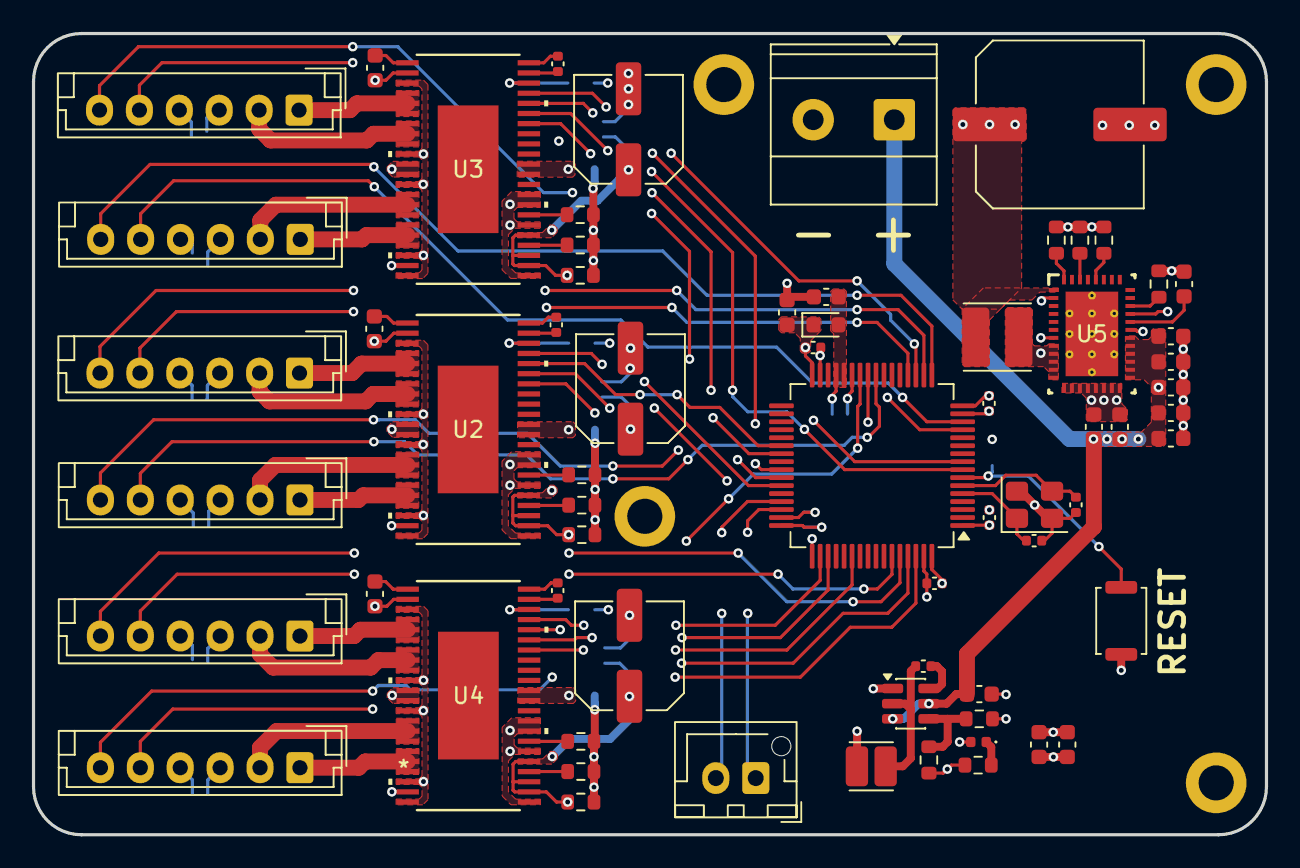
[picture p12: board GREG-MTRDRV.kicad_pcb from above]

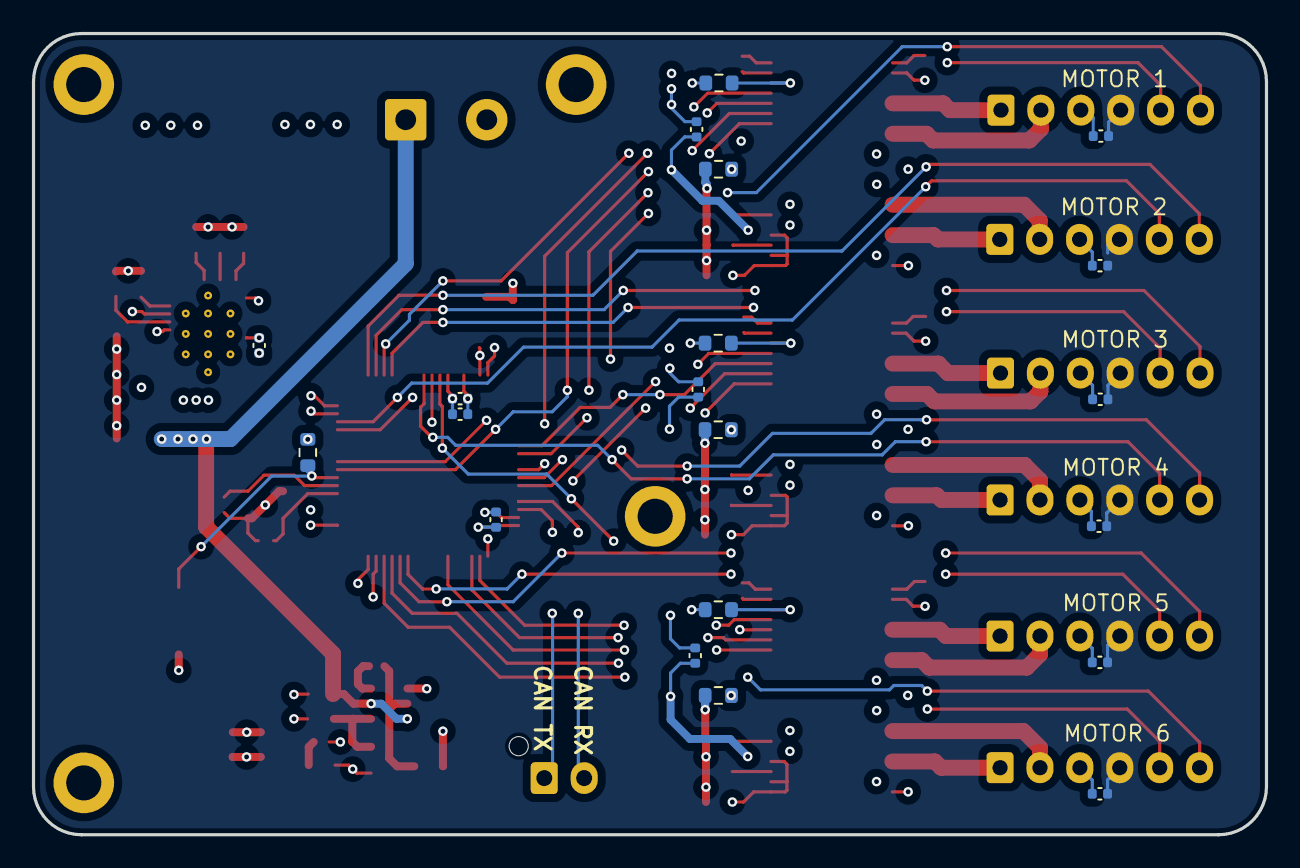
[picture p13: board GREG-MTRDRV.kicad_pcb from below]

Board: 4 copper layers, 77.2 x 50.2 mm, 86 parts (20 on the bottom side), 79 nets.

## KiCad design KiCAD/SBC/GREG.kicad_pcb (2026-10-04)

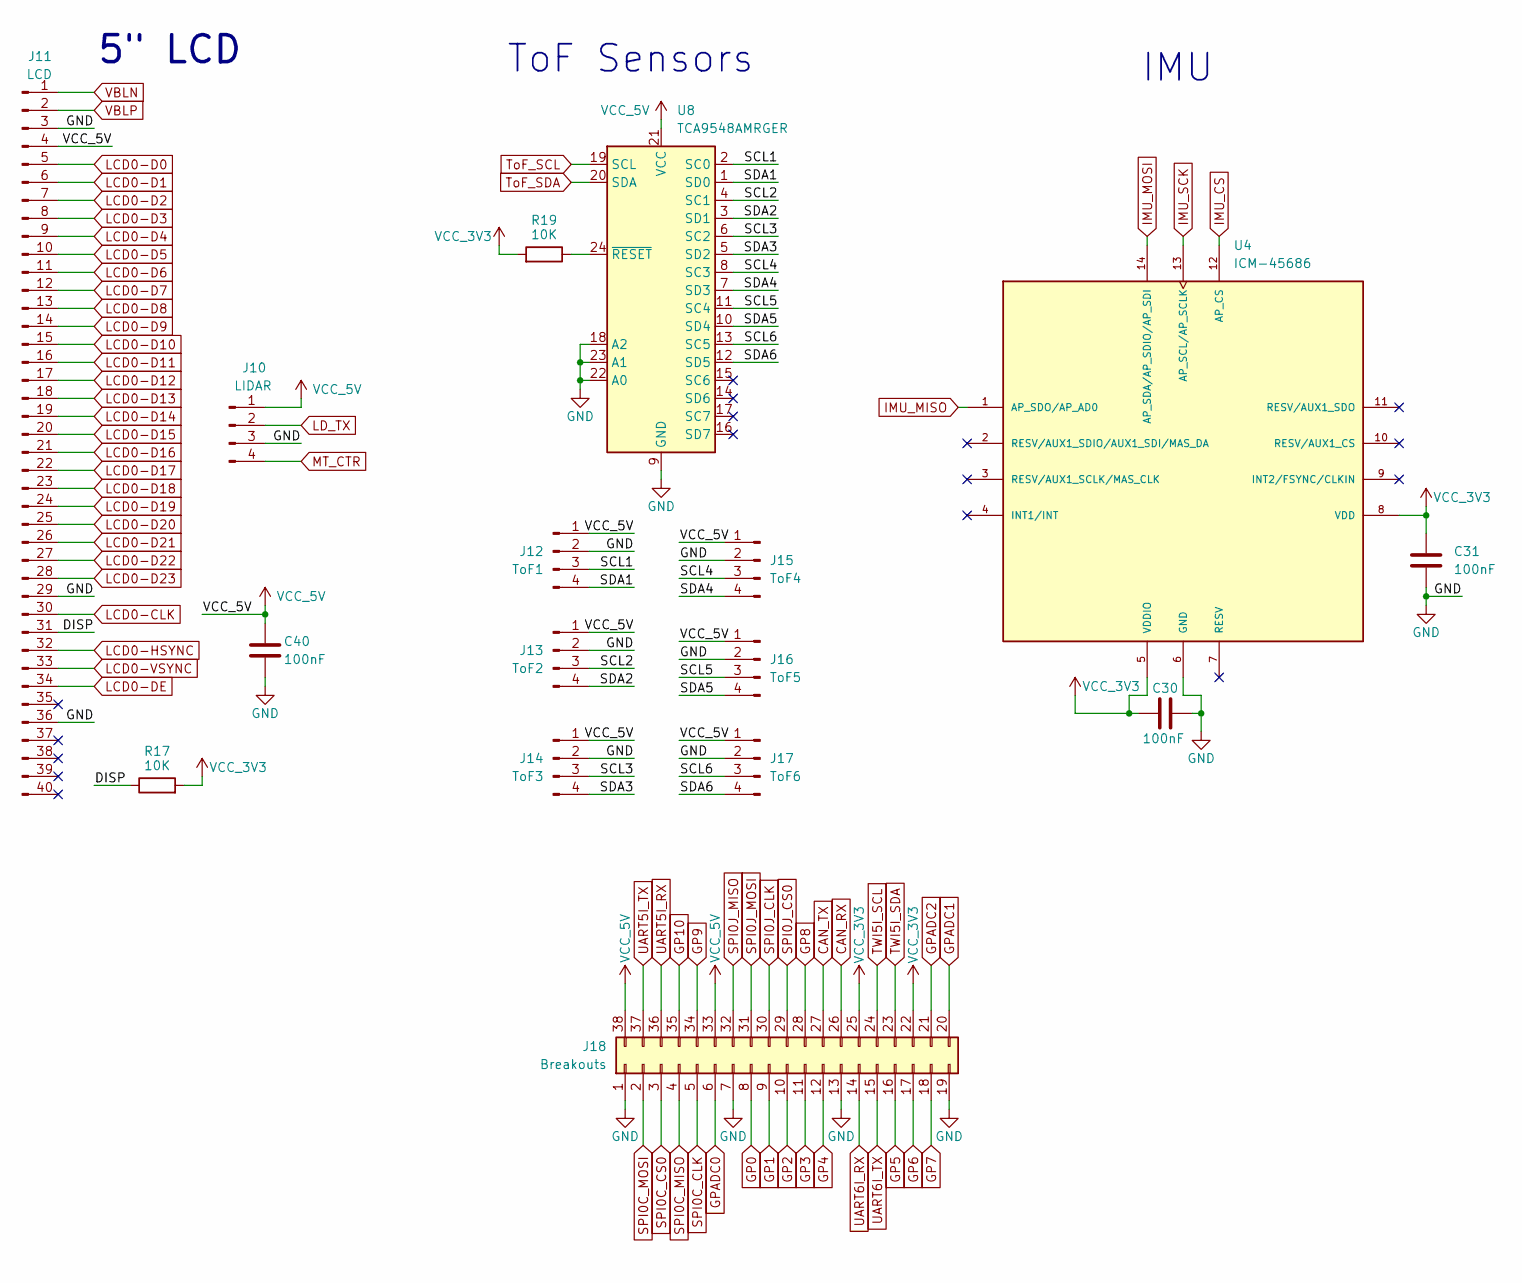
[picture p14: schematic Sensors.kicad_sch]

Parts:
C30, C31, C40: 100nF; C_0402_1005Metric
J10: LIDAR; JST_EH_B4B-EH-A_1x04_P2.50mm_Vertical
J11: LCD; TE_4-1734839-0_1x40-1MP_P0.5mm_Horizontal
J12: ToF1; JST_EH_B4B-EH-A_1x04_P2.50mm_Vertical
J13: ToF2; JST_EH_B4B-EH-A_1x04_P2.50mm_Vertical
J14: ToF3; JST_EH_B4B-EH-A_1x04_P2.50mm_Vertical
J15: ToF4; JST_EH_B4B-EH-A_1x04_P2.50mm_Vertical
J16: ToF5; JST_EH_B4B-EH-A_1x04_P2.50mm_Vertical
J17: ToF6; JST_EH_B4B-EH-A_1x04_P2.50mm_Vertical
J18: Breakouts; PinHeader_2x19_P2.54mm_Vertical
R17, R19: 10K; R_0402_1005Metric
U4: ICM-45686; IC_ICM-45686
U8: TCA9548AMRGER; Texas_RGE0024C_VQFN-24-1EP_4x4mm_P0.5mm_EP2.1x2.1mm

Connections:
/Sensors/DISP: J11.31, R17.1
/Sensors/SCL1: J12.3, U8.2 (SC0)
/Sensors/SCL2: J13.3, U8.4 (SC1)
/Sensors/SCL3: J14.3, U8.6 (SC2)
/Sensors/SCL4: J15.3, U8.8 (SC3)
/Sensors/SCL5: J16.3, U8.11 (SC4)
/Sensors/SCL6: J17.3, U8.13 (SC5)
/Sensors/SDA1: J12.4, U8.1 (SD0)
/Sensors/SDA2: J13.4, U8.3 (SD1)
/Sensors/SDA3: J14.4, U8.5 (SD2)
/Sensors/SDA4: J15.4, U8.7 (SD3)
/Sensors/SDA5: J16.4, U8.10 (SD4)
/Sensors/SDA6: J17.4, U8.12 (SD5)
CAN_RX: J18.26; also elsewhere on the board
CAN_TX: J18.27; also elsewhere on the board
GND: C30.2, C31.2, C40.2, J10.3, J11.3, J11.29, J11.36, J12.2, J13.2, J14.2, J15.2, J16.2, J17.2, J18.1, J18.7, J18.13, J18.19, U4.6 (GND), U8.9 (GND), U8.18 (A2), U8.22 (A0), U8.23 (A1); also elsewhere on the board
GP0: J18.8; also elsewhere on the board
GP1: J18.9; also elsewhere on the board
GP2: J18.10; also elsewhere on the board
GP3: J18.11; also elsewhere on the board
GP4: J18.12; also elsewhere on the board
GP5: J18.16; also elsewhere on the board
GP6: J18.17; also elsewhere on the board
GP7: J18.18; also elsewhere on the board
GP8: J18.28; also elsewhere on the board
GP9: J18.34; also elsewhere on the board
GP10: J18.35; also elsewhere on the board
GPADC0: J18.6; also elsewhere on the board
GPADC1: J18.20; also elsewhere on the board
GPADC2: J18.21; also elsewhere on the board
IMU_CS: U4.12 (AP_CS); also elsewhere on the board
IMU_MISO: U4.1 (AP_SDO/AP_AD0); also elsewhere on the board
IMU_MOSI: U4.14 (AP_SDA/AP_SDIO/AP_SDI); also elsewhere on the board
IMU_SCK: U4.13 (AP_SCL/AP_SCLK); also elsewhere on the board
LCD0-CLK: J11.30; also elsewhere on the board
LCD0-D0: J11.5; also elsewhere on the board
LCD0-D1: J11.6; also elsewhere on the board
LCD0-D2: J11.7; also elsewhere on the board
LCD0-D3: J11.8; also elsewhere on the board
LCD0-D4: J11.9; also elsewhere on the board
LCD0-D5: J11.10; also elsewhere on the board
LCD0-D6: J11.11; also elsewhere on the board
LCD0-D7: J11.12; also elsewhere on the board
LCD0-D8: J11.13; also elsewhere on the board
LCD0-D9: J11.14; also elsewhere on the board
LCD0-D10: J11.15; also elsewhere on the board
LCD0-D11: J11.16; also elsewhere on the board
LCD0-D12: J11.17; also elsewhere on the board
LCD0-D13: J11.18; also elsewhere on the board
LCD0-D14: J11.19; also elsewhere on the board
LCD0-D15: J11.20; also elsewhere on the board
LCD0-D16: J11.21; also elsewhere on the board
LCD0-D17: J11.22; also elsewhere on the board
LCD0-D18: J11.23; also elsewhere on the board
LCD0-D19: J11.24; also elsewhere on the board
LCD0-D20: J11.25; also elsewhere on the board
LCD0-D21: J11.26; also elsewhere on the board
LCD0-D22: J11.27; also elsewhere on the board
LCD0-D23: J11.28; also elsewhere on the board
LCD0-DE: J11.34; also elsewhere on the board
LCD0-HSYNC: J11.32; also elsewhere on the board
LCD0-VSYNC: J11.33; also elsewhere on the board
LD_TX: J10.2; also elsewhere on the board
MT_CTR: J10.4; also elsewhere on the board
unnamed: R19.1, U8.24 (~RESET)
SPI0C_CLK: J18.5; also elsewhere on the board
SPI0C_CS0: J18.3; also elsewhere on the board
SPI0C_MISO: J18.4; also elsewhere on the board
SPI0C_MOSI: J18.2; also elsewhere on the board
SPI0J_CLK: J18.30; also elsewhere on the board
SPI0J_CS0: J18.29; also elsewhere on the board
SPI0J_MISO: J18.32; also elsewhere on the board
SPI0J_MOSI: J18.31; also elsewhere on the board
TWI5I_SCL: J18.24; also elsewhere on the board
TWI5I_SDA: J18.23; also elsewhere on the board
ToF_SCL: U8.19 (SCL); also elsewhere on the board
ToF_SDA: U8.20 (SDA); also elsewhere on the board
UART5I_RX: J18.36; also elsewhere on the board
UART5I_TX: J18.37; also elsewhere on the board
UART6I_RX: J18.14; also elsewhere on the board
UART6I_TX: J18.15; also elsewhere on the board
VBLN: J11.1; also elsewhere on the board
VBLP: J11.2; also elsewhere on the board
VCC_3V3: C30.1, C31.1, J18.22, J18.25, R17.2, R19.2, U4.5 (VDDIO), U4.8 (VDD); also elsewhere on the board
VCC_5V: C40.1, J10.1, J11.4, J12.1, J13.1, J14.1, J15.1, J16.1, J17.1, J18.33, J18.38, U8.21 (VCC); also elsewhere on the board

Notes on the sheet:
5" LCD
ToF Sensors
IMU

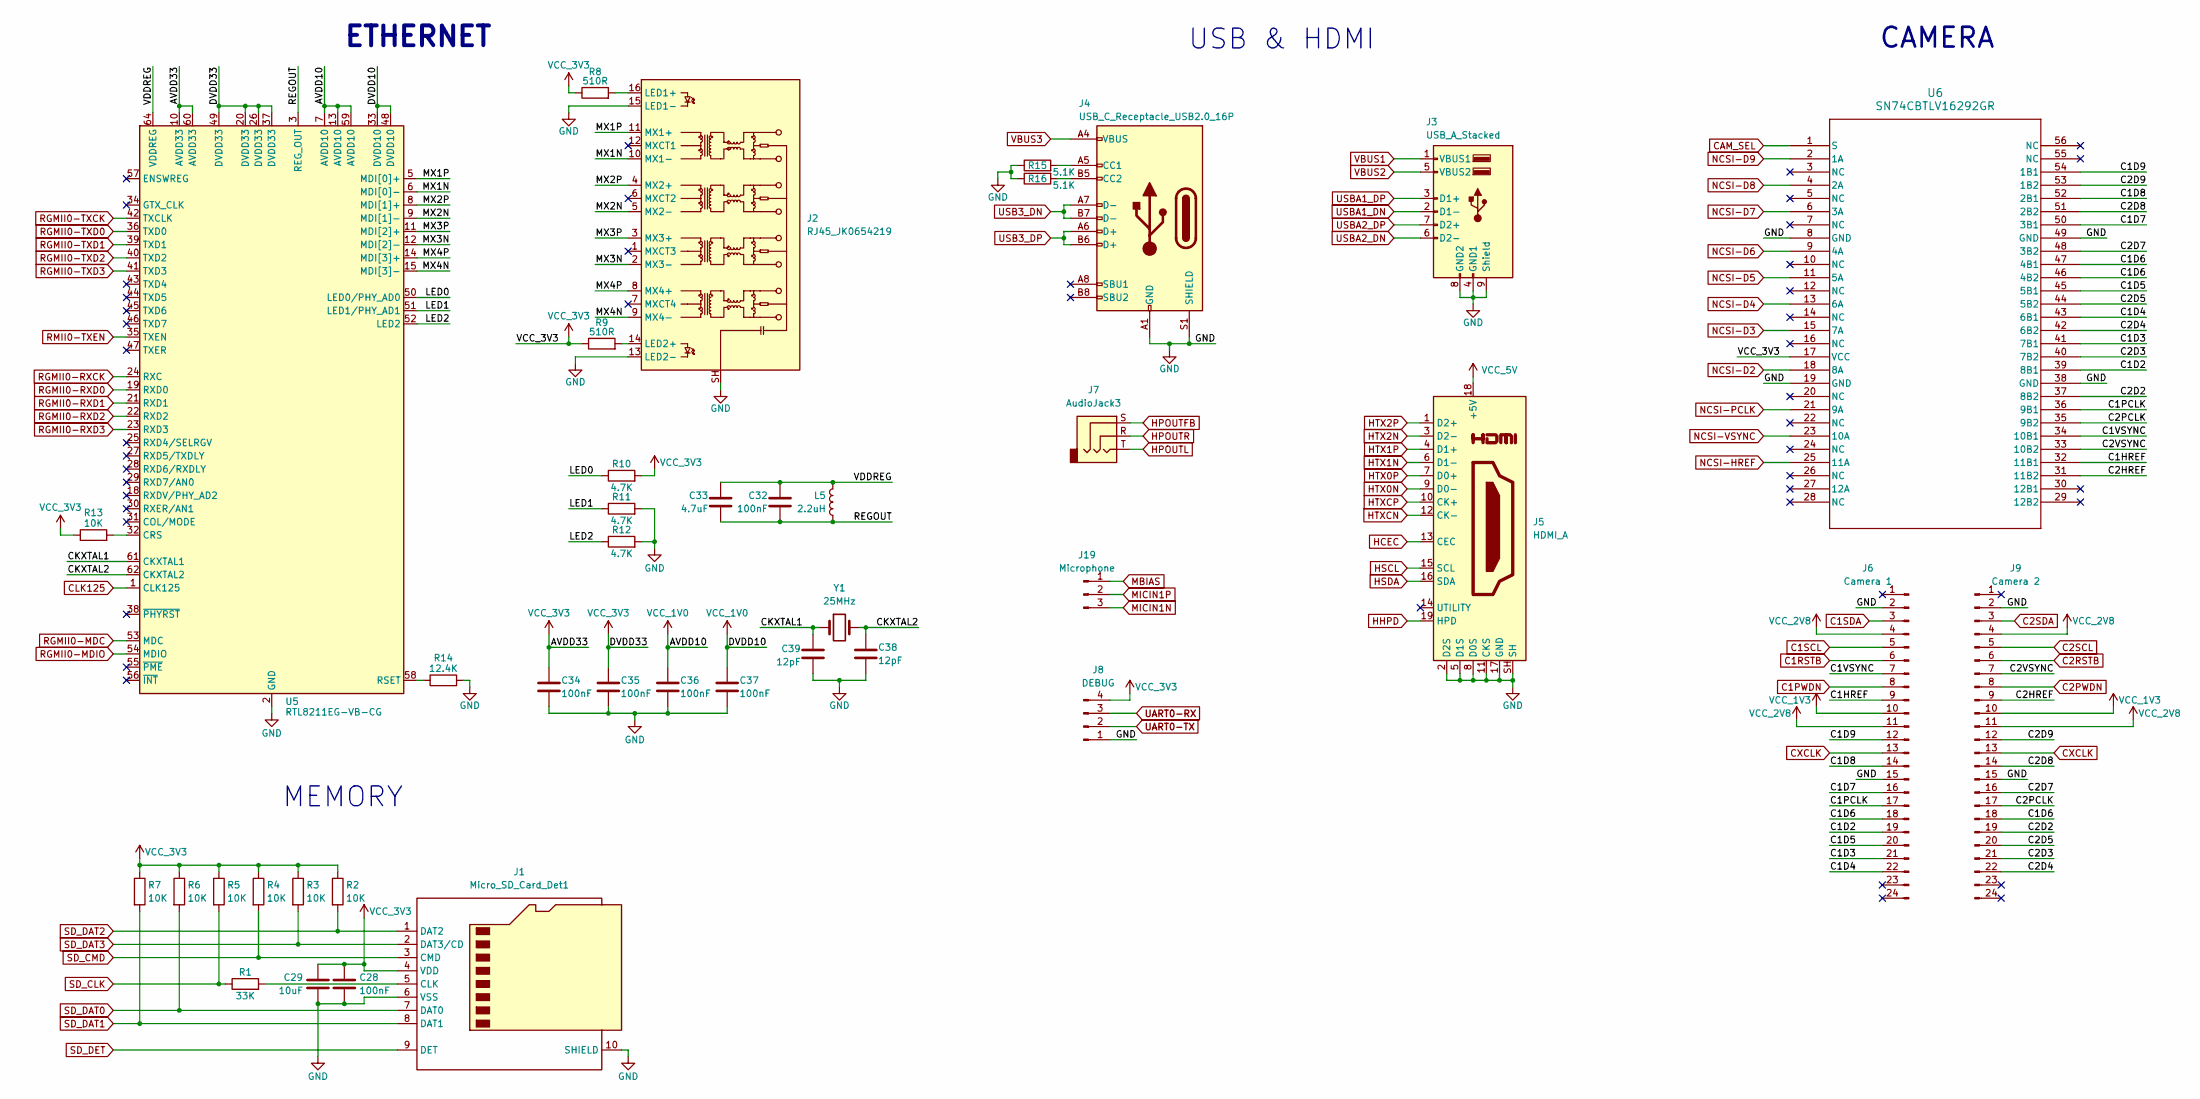
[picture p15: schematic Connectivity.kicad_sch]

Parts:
C28, C32, C34, C35, C36, C37: 100nF; C_0402_1005Metric
C29: 10uF; C_0805_2012Metric
C33: 4.7uF; C_0805_2012Metric
C38, C39: 12pF; C_0402_1005Metric
J1: Micro_SD_Card_Det1; microSD_HC_Wuerth
J2: RJ45_JK0654219; RJ45_Pulse_JK0654219NL_Horizontal
J3: USB_A_Stacked; USB_A_CUI_UJ2-ADH-TH_Horizontal_Stacked
J4: USB_C_Receptacle_USB2.0_16P; USB_C_Receptacle_HRO_TYPE-C-31-M-12
J5: HDMI_A; HDMI_Micro-D_Molex_46765-1xxx
J6: Camera 1; Molex_502231-2400_1x24-1SH_P0.5mm_Vertical
J7: AudioJack3; Jack_3.5mm_CUI_SJ-3523-SMT_Horizontal
J8: DEBUG; JST_EH_B4B-EH-A_1x04_P2.50mm_Vertical
J9: Camera 2; Molex_502231-2400_1x24-1SH_P0.5mm_Vertical
J19: Microphone; JST_EH_B3B-EH-A_1x03_P2.50mm_Vertical
L5: 2.2uH; L_Cenker_CKCS3015
R1: 33K; R_0402_1005Metric
R2, R3, R4, R5, R6, R7, R13: 10K; R_0402_1005Metric
R8, R9: 510R; R_0402_1005Metric
R10, R11, R12: 4.7K; R_0402_1005Metric
R14: 12.4K; R_0402_1005Metric
R15, R16: 5.1K; R_0402_1005Metric
U5: RTL8211EG-VB-CG; RTL
U6: SN74CBTLV16292GR; DGG56
Y1: 25MHz; Crystal_SMD_3215-2Pin_3.2x1.5mm

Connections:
/Connectivity/C1D2: J6.19, U6.39 (8B1)
/Connectivity/C1D3: J6.21, U6.41 (7B1)
/Connectivity/C1D4: J6.22, U6.43 (6B1)
/Connectivity/C1D5: J6.20, U6.45 (5B1)
/Connectivity/C1D6: J6.18, J9.18, U6.46 (4B2), U6.47 (4B1)
/Connectivity/C1D7: J6.16, U6.50 (3B1)
/Connectivity/C1D8: J6.14, U6.52 (2B1)
/Connectivity/C1D9: J6.12, U6.54 (1B1)
/Connectivity/C1HREF: J6.9, U6.32 (11B1)
/Connectivity/C1PCLK: J6.17, U6.36 (9B1)
/Connectivity/C1VSYNC: J6.7, U6.34 (10B1)
/Connectivity/C2D2: J9.19, U6.37 (8B2)
/Connectivity/C2D3: J9.21, U6.40 (7B2)
/Connectivity/C2D4: J9.22, U6.42 (6B2)
/Connectivity/C2D5: J9.20, U6.44 (5B2)
/Connectivity/C2D7: J9.16, U6.48 (3B2)
/Connectivity/C2D8: J9.14, U6.51 (2B2)
/Connectivity/C2D9: J9.12, U6.53 (1B2)
/Connectivity/C2HREF: J9.9, U6.31 (11B2)
/Connectivity/C2PCLK: J9.17, U6.35 (9B2)
/Connectivity/C2VSYNC: J9.7, U6.33 (10B2)
/Connectivity/CKXTAL1: C39.1, U5.61 (CKXTAL1), Y1.1
/Connectivity/CKXTAL2: C38.1, U5.62 (CKXTAL2), Y1.2
/Connectivity/LED0: R10.1, U5.50 (LED0/PHY_AD0)
/Connectivity/LED1: R11.1, U5.51 (LED1/PHY_AD1)
/Connectivity/LED2: R12.1, U5.52 (LED2)
/Connectivity/MX1N: J2.10 (MX1-), U5.6 (MDI[0]-)
/Connectivity/MX1P: J2.11 (MX1+), U5.5 (MDI[0]+)
/Connectivity/MX2N: J2.5 (MX2-), U5.9 (MDI[1]-)
/Connectivity/MX2P: J2.4 (MX2+), U5.8 (MDI[1]+)
/Connectivity/MX3N: J2.2 (MX3-), U5.12 (MDI[2]-)
/Connectivity/MX3P: J2.3 (MX3+), U5.11 (MDI[2]+)
/Connectivity/MX4N: J2.9 (MX4-), U5.15 (MDI[3]-)
/Connectivity/MX4P: J2.8 (MX4+), U5.14 (MDI[3]+)
/Connectivity/REGOUT: C32.2, C33.2, L5.2, U5.3 (REG_OUT)
/Connectivity/VDDREG: C32.1, C33.1, L5.1, U5.64 (VDDREG)
C1PWDN: J6.8; also elsewhere on the board
C1RSTB: J6.6; also elsewhere on the board
C1SCL: J6.5; also elsewhere on the board
C1SDA: J6.3; also elsewhere on the board
C2PWDN: J9.8; also elsewhere on the board
C2RSTB: J9.6; also elsewhere on the board
C2SCL: J9.5; also elsewhere on the board
C2SDA: J9.3; also elsewhere on the board
CAM_SEL: U6.1 (S); also elsewhere on the board
CLK125: U5.1 (CLK125); also elsewhere on the board
CXCLK: J6.13, J9.13; also elsewhere on the board
GND: C28.2, C29.2, C34.2, C35.2, C36.2, C37.2, C38.2, C39.2, J1.6 (VSS), J1.10 (SHIELD), J2.13 (LED2-), J2.15 (LED1-), J2.SH, J3.4 (GND1), J3.8 (GND2), J3.9 (Shield), J4.A1 (GND), J4.A12 (GND), J4.B1 (GND), J4.B12 (GND), J4.S1 (SHIELD), J5.2 (D2S), J5.5 (D1S), J5.8 (D0S), J5.11 (CKS), J5.17 (GND), J5.SH, J6.2, J6.15, J8.1, J9.2, J9.15, R11.2, R12.2, R14.2, R15.1, R16.1, U5.2 (GND), U5.4 (GND), U5.63 (GND), U5.65 (GND), U6.8 (GND), U6.19 (GND), U6.38 (GND), U6.49 (GND); also elsewhere on the board
HCEC: J5.13 (CEC); also elsewhere on the board
HHPD: J5.19 (HPD); also elsewhere on the board
HPOUTFB: J7.S; also elsewhere on the board
HPOUTL: J7.T; also elsewhere on the board
HPOUTR: J7.R; also elsewhere on the board
HSCL: J5.15 (SCL); also elsewhere on the board
HSDA: J5.16 (SDA); also elsewhere on the board
HTX0N: J5.9 (D0-); also elsewhere on the board
HTX0P: J5.7 (D0+); also elsewhere on the board
HTX1N: J5.6 (D1-); also elsewhere on the board
HTX1P: J5.4 (D1+); also elsewhere on the board
HTX2N: J5.3 (D2-); also elsewhere on the board
HTX2P: J5.1 (D2+); also elsewhere on the board
HTXCN: J5.12 (CK-); also elsewhere on the board
HTXCP: J5.10 (CK+); also elsewhere on the board
MBIAS: J19.1; also elsewhere on the board
MICIN1N: J19.3; also elsewhere on the board
MICIN1P: J19.2; also elsewhere on the board
NCSI-D2: U6.18 (8A); also elsewhere on the board
NCSI-D3: U6.15 (7A); also elsewhere on the board
NCSI-D4: U6.13 (6A); also elsewhere on the board
NCSI-D5: U6.11 (5A); also elsewhere on the board
NCSI-D6: U6.9 (4A); also elsewhere on the board
NCSI-D7: U6.6 (3A); also elsewhere on the board
NCSI-D8: U6.4 (2A); also elsewhere on the board
NCSI-D9: U6.2 (1A); also elsewhere on the board
NCSI-HREF: U6.25 (11A); also elsewhere on the board
NCSI-PCLK: U6.21 (9A); also elsewhere on the board
NCSI-VSYNC: U6.23 (10A); also elsewhere on the board
unnamed: J1.5 (CLK), R1.2
unnamed: J2.16 (LED1+), R8.2
unnamed: J2.14 (LED2+), R9.2
unnamed: J4.A5 (CC1), R15.2
unnamed: J4.B5 (CC2), R16.2
unnamed: R13.2, U5.32 (CRS)
unnamed: R14.1, U5.58 (RSET)
RGMII0-MDC: U5.53 (MDC); also elsewhere on the board
RGMII0-MDIO: U5.54 (MDIO); also elsewhere on the board
RGMII0-RXCK: U5.24 (RXC); also elsewhere on the board
RGMII0-RXD0: U5.19 (RXD0); also elsewhere on the board
RGMII0-RXD1: U5.21 (RXD1); also elsewhere on the board
RGMII0-RXD2: U5.22 (RXD2); also elsewhere on the board
RGMII0-RXD3: U5.23 (RXD3); also elsewhere on the board
RGMII0-TXCK: U5.42 (TXCLK); also elsewhere on the board
RGMII0-TXD0: U5.36 (TXD0); also elsewhere on the board
RGMII0-TXD1: U5.39 (TXD1); also elsewhere on the board
RGMII0-TXD2: U5.40 (TXD2); also elsewhere on the board
RGMII0-TXD3: U5.41 (TXD3)
RMII0-TXEN: U5.35 (TXEN); also elsewhere on the board
SD_CLK: R1.1, R5.2
SD_CMD: J1.3 (CMD), R4.2
SD_DAT0: J1.7 (DAT0), R6.2
SD_DAT1: J1.8 (DAT1), R7.2
SD_DAT2: J1.1 (DAT2), R2.2
SD_DAT3: J1.2 (DAT3/CD), R3.2
SD_DET: J1.9 (DET)
UART0-RX: J8.3; also elsewhere on the board
UART0-TX: J8.2; also elsewhere on the board
USB3_DN: J4.A7 (D-), J4.B7 (D-); also elsewhere on the board
USB3_DP: J4.A6 (D+), J4.B6 (D+); also elsewhere on the board
USBA1_DN: J3.2 (D1-); also elsewhere on the board
USBA1_DP: J3.3 (D1+); also elsewhere on the board
USBA2_DN: J3.6 (D2-); also elsewhere on the board
USBA2_DP: J3.7 (D2+); also elsewhere on the board
VBUS1: J3.1 (VBUS1)
VBUS2: J3.5 (VBUS2)
VBUS3: J4.A4 (VBUS), J4.A9 (VBUS), J4.B4 (VBUS), J4.B9 (VBUS)
VCC_1V0: C36.1, C37.1, U5.7 (AVDD10), U5.13 (AVDD10), U5.33 (DVDD10), U5.48 (DVDD10), U5.59 (AVDD10); also elsewhere on the board
VCC_1V3: J6.10, J9.10; also elsewhere on the board
VCC_2V8: J6.4, J6.11, J9.4, J9.11; also elsewhere on the board
VCC_3V3: C28.1, C29.1, C34.1, C35.1, J1.4 (VDD), J8.4, R2.1, R3.1, R4.1, R5.1, R6.1, R7.1, R8.1, R9.1, R10.2, R13.1, U5.10 (AVDD33), U5.20 (DVDD33), U5.26 (DVDD33), U5.37 (DVDD33), U5.49 (DVDD33), U5.60 (AVDD33), U6.17 (VCC); also elsewhere on the board
VCC_5V: J5.18 (+5V); also elsewhere on the board

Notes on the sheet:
ETHERNET
CAMERA
USB & HDMI
MEMORY

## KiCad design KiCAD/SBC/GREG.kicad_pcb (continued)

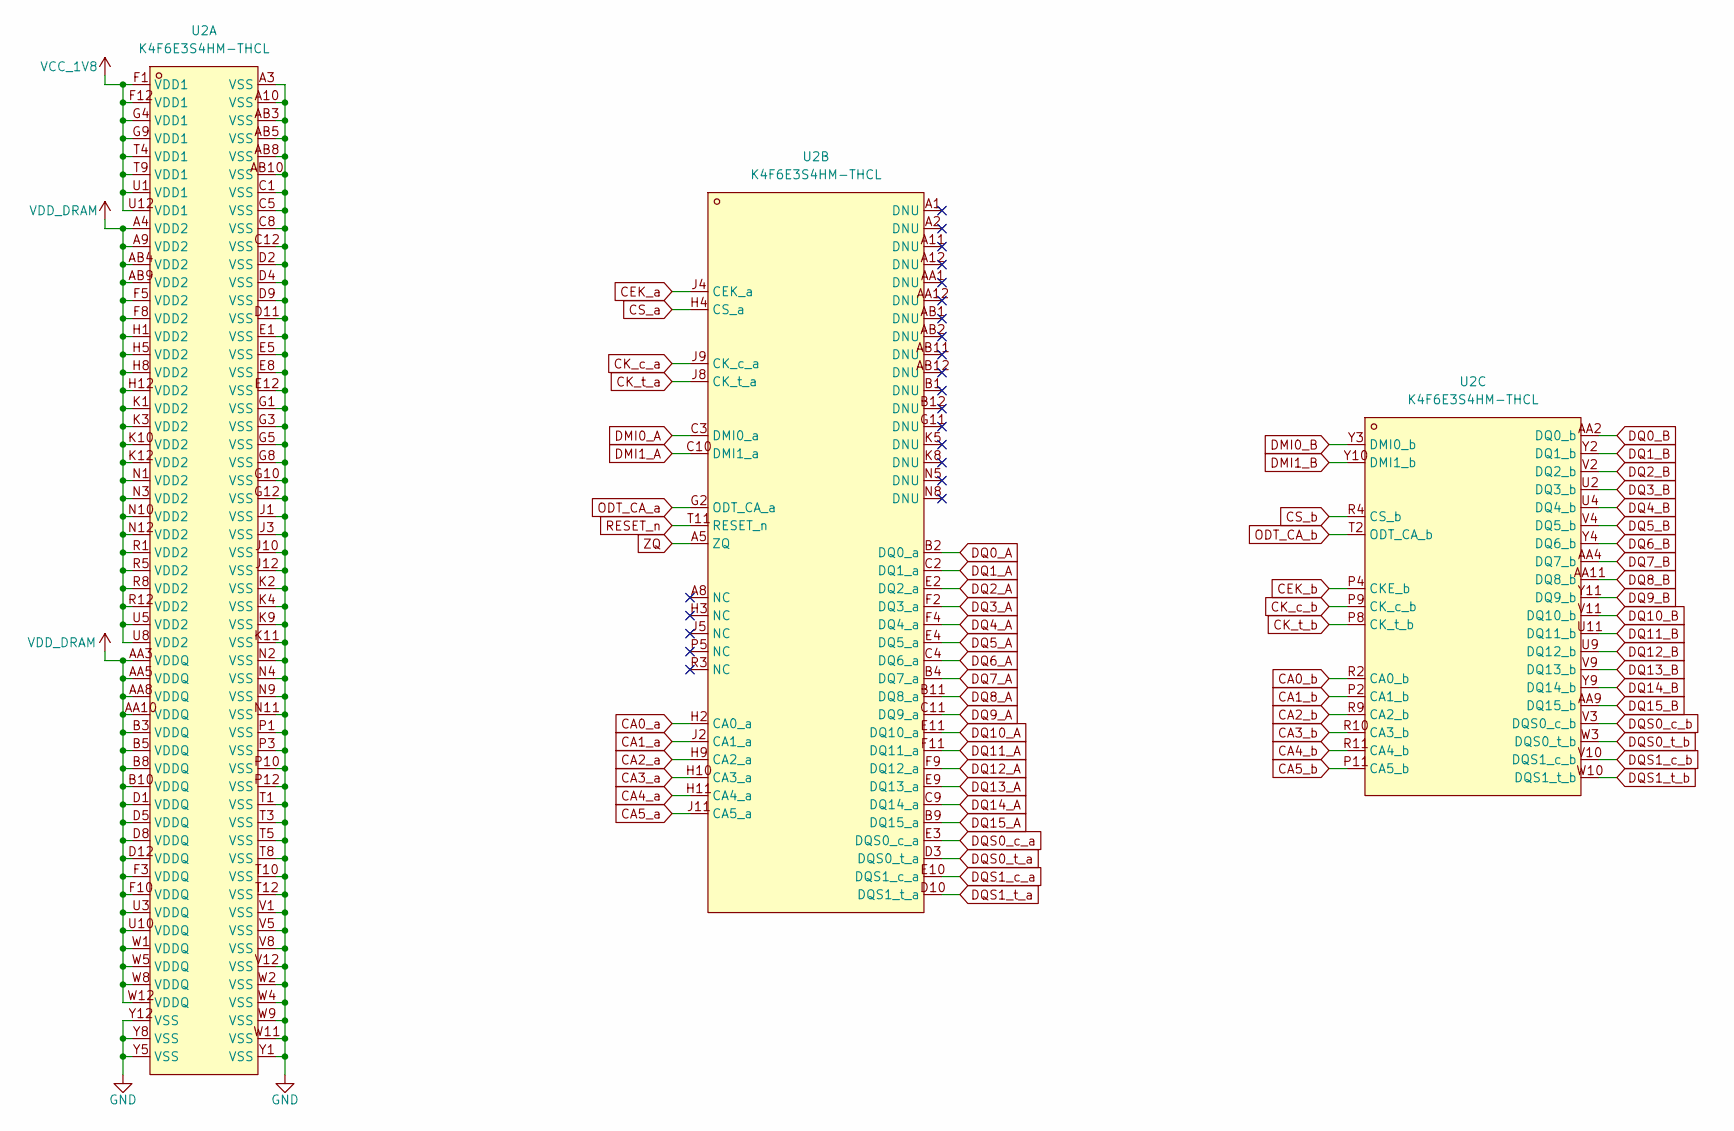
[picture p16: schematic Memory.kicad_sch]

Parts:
U2: K4F6E3S4HM-THCL; FBGA-200_L15.0-W10.0-BL_K4F6E3S4HM; MPN K4F6E3S4HM-THCL; LCSC Part C2920224

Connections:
CA0_a: U2.H2 (CA0_a); also elsewhere on the board
CA0_b: U2.R2 (CA0_b); also elsewhere on the board
CA1_a: U2.J2 (CA1_a); also elsewhere on the board
CA1_b: U2.P2 (CA1_b); also elsewhere on the board
CA2_a: U2.H9 (CA2_a); also elsewhere on the board
CA2_b: U2.R9 (CA2_b); also elsewhere on the board
CA3_a: U2.H10 (CA3_a); also elsewhere on the board
CA3_b: U2.R10 (CA3_b); also elsewhere on the board
CA4_a: U2.H11 (CA4_a); also elsewhere on the board
CA4_b: U2.R11 (CA4_b); also elsewhere on the board
CA5_a: U2.J11 (CA5_a); also elsewhere on the board
CA5_b: U2.P11 (CA5_b); also elsewhere on the board
CEK_a: U2.J4 (CEK_a), U2.P4 (CKE_b); also elsewhere on the board
CK_c_a: U2.J9 (CK_c_a), U2.P9 (CK_c_b); also elsewhere on the board
CK_t_a: U2.J8 (CK_t_a), U2.P8 (CK_t_b); also elsewhere on the board
CS_a: U2.H4 (CS_a); also elsewhere on the board
CS_b: U2.R4 (CS_b); also elsewhere on the board
DMI0_A: U2.C3 (DMI0_a); also elsewhere on the board
DMI0_B: U2.Y3 (DMI0_b); also elsewhere on the board
DMI1_A: U2.C10 (DMI1_a); also elsewhere on the board
DMI1_B: U2.Y10 (DMI1_b); also elsewhere on the board
DQ0_A: U2.B2 (DQ0_a); also elsewhere on the board
DQ0_B: U2.AA2 (DQ0_b); also elsewhere on the board
DQ1_A: U2.C2 (DQ1_a); also elsewhere on the board
DQ1_B: U2.Y2 (DQ1_b); also elsewhere on the board
DQ2_A: U2.E2 (DQ2_a); also elsewhere on the board
DQ2_B: U2.V2 (DQ2_b); also elsewhere on the board
DQ3_A: U2.F2 (DQ3_a); also elsewhere on the board
DQ3_B: U2.U2 (DQ3_b); also elsewhere on the board
DQ4_A: U2.F4 (DQ4_a); also elsewhere on the board
DQ4_B: U2.U4 (DQ4_b); also elsewhere on the board
DQ5_A: U2.E4 (DQ5_a); also elsewhere on the board
DQ5_B: U2.V4 (DQ5_b); also elsewhere on the board
DQ6_A: U2.C4 (DQ6_a); also elsewhere on the board
DQ6_B: U2.Y4 (DQ6_b); also elsewhere on the board
DQ7_A: U2.B4 (DQ7_a); also elsewhere on the board
DQ7_B: U2.AA4 (DQ7_b); also elsewhere on the board
DQ8_A: U2.B11 (DQ8_a); also elsewhere on the board
DQ8_B: U2.AA11 (DQ8_b); also elsewhere on the board
DQ9_A: U2.C11 (DQ9_a); also elsewhere on the board
DQ9_B: U2.Y11 (DQ9_b); also elsewhere on the board
DQ10_A: U2.E11 (DQ10_a); also elsewhere on the board
DQ10_B: U2.V11 (DQ10_b); also elsewhere on the board
DQ11_A: U2.F11 (DQ11_a); also elsewhere on the board
DQ11_B: U2.U11 (DQ11_b); also elsewhere on the board
DQ12_A: U2.F9 (DQ12_a); also elsewhere on the board
DQ12_B: U2.U9 (DQ12_b); also elsewhere on the board
DQ13_A: U2.E9 (DQ13_a); also elsewhere on the board
DQ13_B: U2.V9 (DQ13_b); also elsewhere on the board
DQ14_A: U2.C9 (DQ14_a); also elsewhere on the board
DQ14_B: U2.Y9 (DQ14_b); also elsewhere on the board
DQ15_A: U2.B9 (DQ15_a); also elsewhere on the board
DQ15_B: U2.AA9 (DQ15_b); also elsewhere on the board
DQS0_c_a: U2.E3 (DQS0_c_a); also elsewhere on the board
DQS0_c_b: U2.V3 (DQS0_c_b)
DQS0_t_a: U2.D3 (DQS0_t_a); also elsewhere on the board
DQS0_t_b: U2.W3 (DQS0_t_b)
DQS1_c_a: U2.E10 (DQS1_c_a); also elsewhere on the board
DQS1_c_b: U2.V10 (DQS1_c_b)
DQS1_t_a: U2.D10 (DQS1_t_a); also elsewhere on the board
DQS1_t_b: U2.W10 (DQS1_t_b)
GND: U2.A3 (VSS), U2.A10 (VSS), U2.AB3 (VSS), U2.AB5 (VSS), U2.AB8 (VSS), U2.AB10 (VSS), U2.C1 (VSS), U2.C5 (VSS), U2.C8 (VSS), U2.C12 (VSS), U2.D2 (VSS), U2.D4 (VSS), U2.D9 (VSS), U2.D11 (VSS), U2.E1 (VSS), U2.E5 (VSS), U2.E8 (VSS), U2.E12 (VSS), U2.G1 (VSS), U2.G3 (VSS), U2.G5 (VSS), U2.G8 (VSS), U2.G10 (VSS), U2.G12 (VSS), U2.J1 (VSS), U2.J3 (VSS), U2.J10 (VSS), U2.J12 (VSS), U2.K2 (VSS), U2.K4 (VSS), U2.K9 (VSS), U2.K11 (VSS), U2.N2 (VSS), U2.N4 (VSS), U2.N9 (VSS), U2.N11 (VSS), U2.P1 (VSS), U2.P3 (VSS), U2.P10 (VSS), U2.P12 (VSS), U2.T1 (VSS), U2.T3 (VSS), U2.T5 (VSS), U2.T8 (VSS), U2.T10 (VSS), U2.T12 (VSS), U2.V1 (VSS), U2.V5 (VSS), U2.V8 (VSS), U2.V12 (VSS), U2.W2 (VSS), U2.W4 (VSS), U2.W9 (VSS), U2.W11 (VSS), U2.Y1 (VSS), U2.Y5 (VSS), U2.Y8 (VSS), U2.Y12 (VSS); also elsewhere on the board
ODT_CA_a: U2.G2 (ODT_CA_a); also elsewhere on the board
ODT_CA_b: U2.T2 (ODT_CA_b); also elsewhere on the board
RESET_n: U2.T11 (RESET_n); also elsewhere on the board
VCC_1V8: U2.F1 (VDD1), U2.F12 (VDD1), U2.G4 (VDD1), U2.G9 (VDD1), U2.T4 (VDD1), U2.T9 (VDD1), U2.U1 (VDD1), U2.U12 (VDD1); also elsewhere on the board
VDD_DRAM: U2.A4 (VDD2), U2.A9 (VDD2), U2.AA3 (VDDQ), U2.AA5 (VDDQ), U2.AA8 (VDDQ), U2.AA10 (VDDQ), U2.AB4 (VDD2), U2.AB9 (VDD2), U2.B3 (VDDQ), U2.B5 (VDDQ), U2.B8 (VDDQ), U2.B10 (VDDQ), U2.D1 (VDDQ), U2.D5 (VDDQ), U2.D8 (VDDQ), U2.D12 (VDDQ), U2.F3 (VDDQ), U2.F5 (VDD2), U2.F8 (VDD2), U2.F10 (VDDQ), U2.H1 (VDD2), U2.H5 (VDD2), U2.H8 (VDD2), U2.H12 (VDD2), U2.K1 (VDD2), U2.K3 (VDD2), U2.K10 (VDD2), U2.K12 (VDD2), U2.N1 (VDD2), U2.N3 (VDD2), U2.N10 (VDD2), U2.N12 (VDD2), U2.R1 (VDD2), U2.R5 (VDD2), U2.R8 (VDD2), U2.R12 (VDD2), U2.U3 (VDDQ), U2.U5 (VDD2), U2.U8 (VDD2), U2.U10 (VDDQ), U2.W1 (VDDQ), U2.W5 (VDDQ), U2.W8 (VDDQ), U2.W12 (VDDQ); also elsewhere on the board
ZQ: U2.A5 (ZQ); also elsewhere on the board

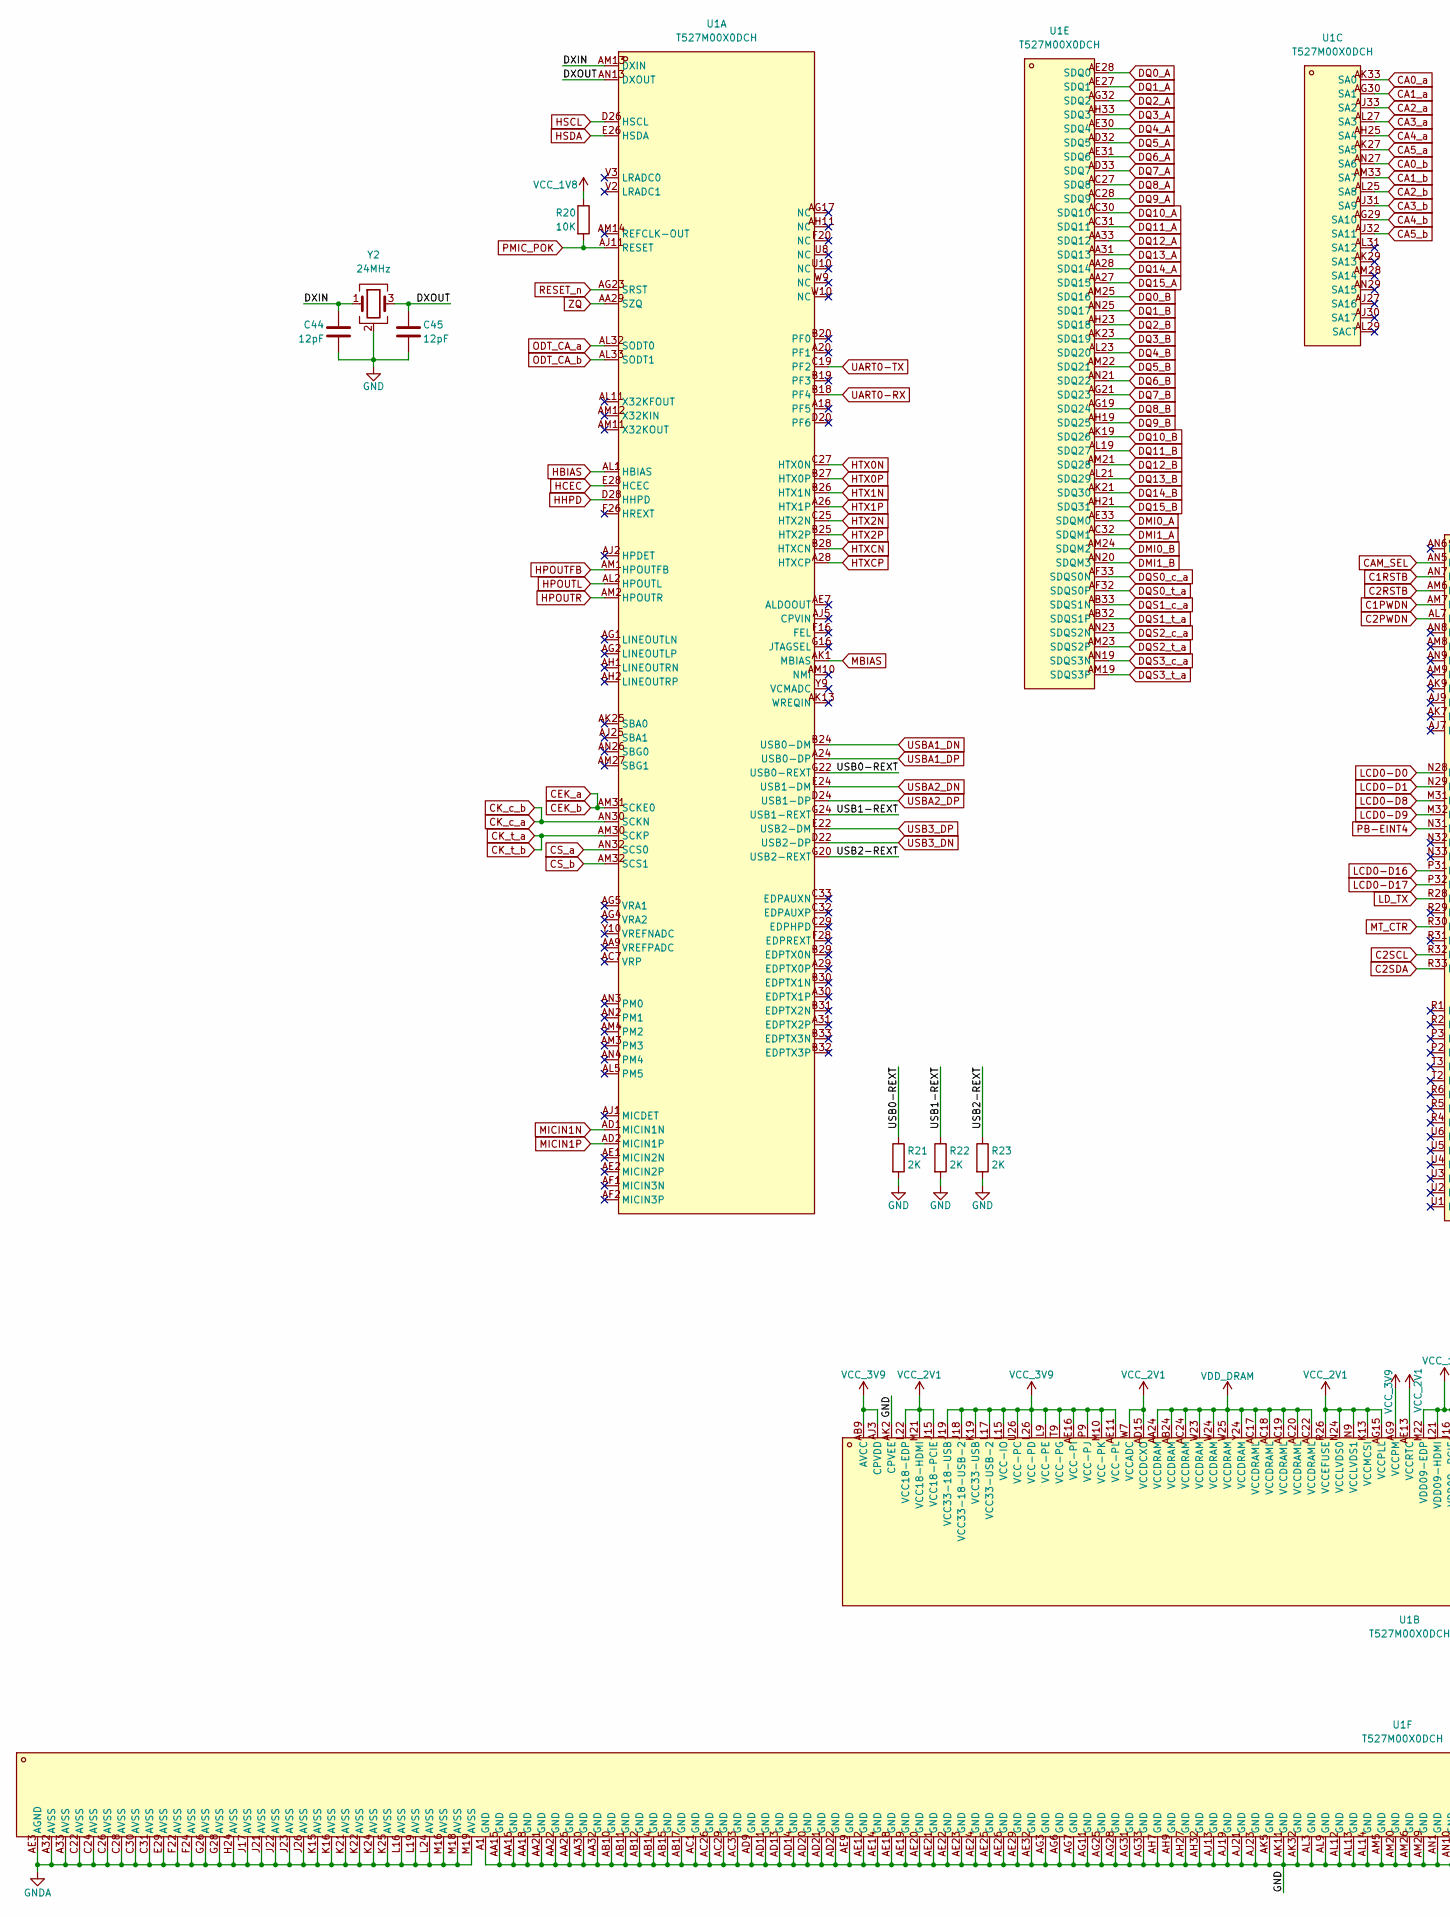
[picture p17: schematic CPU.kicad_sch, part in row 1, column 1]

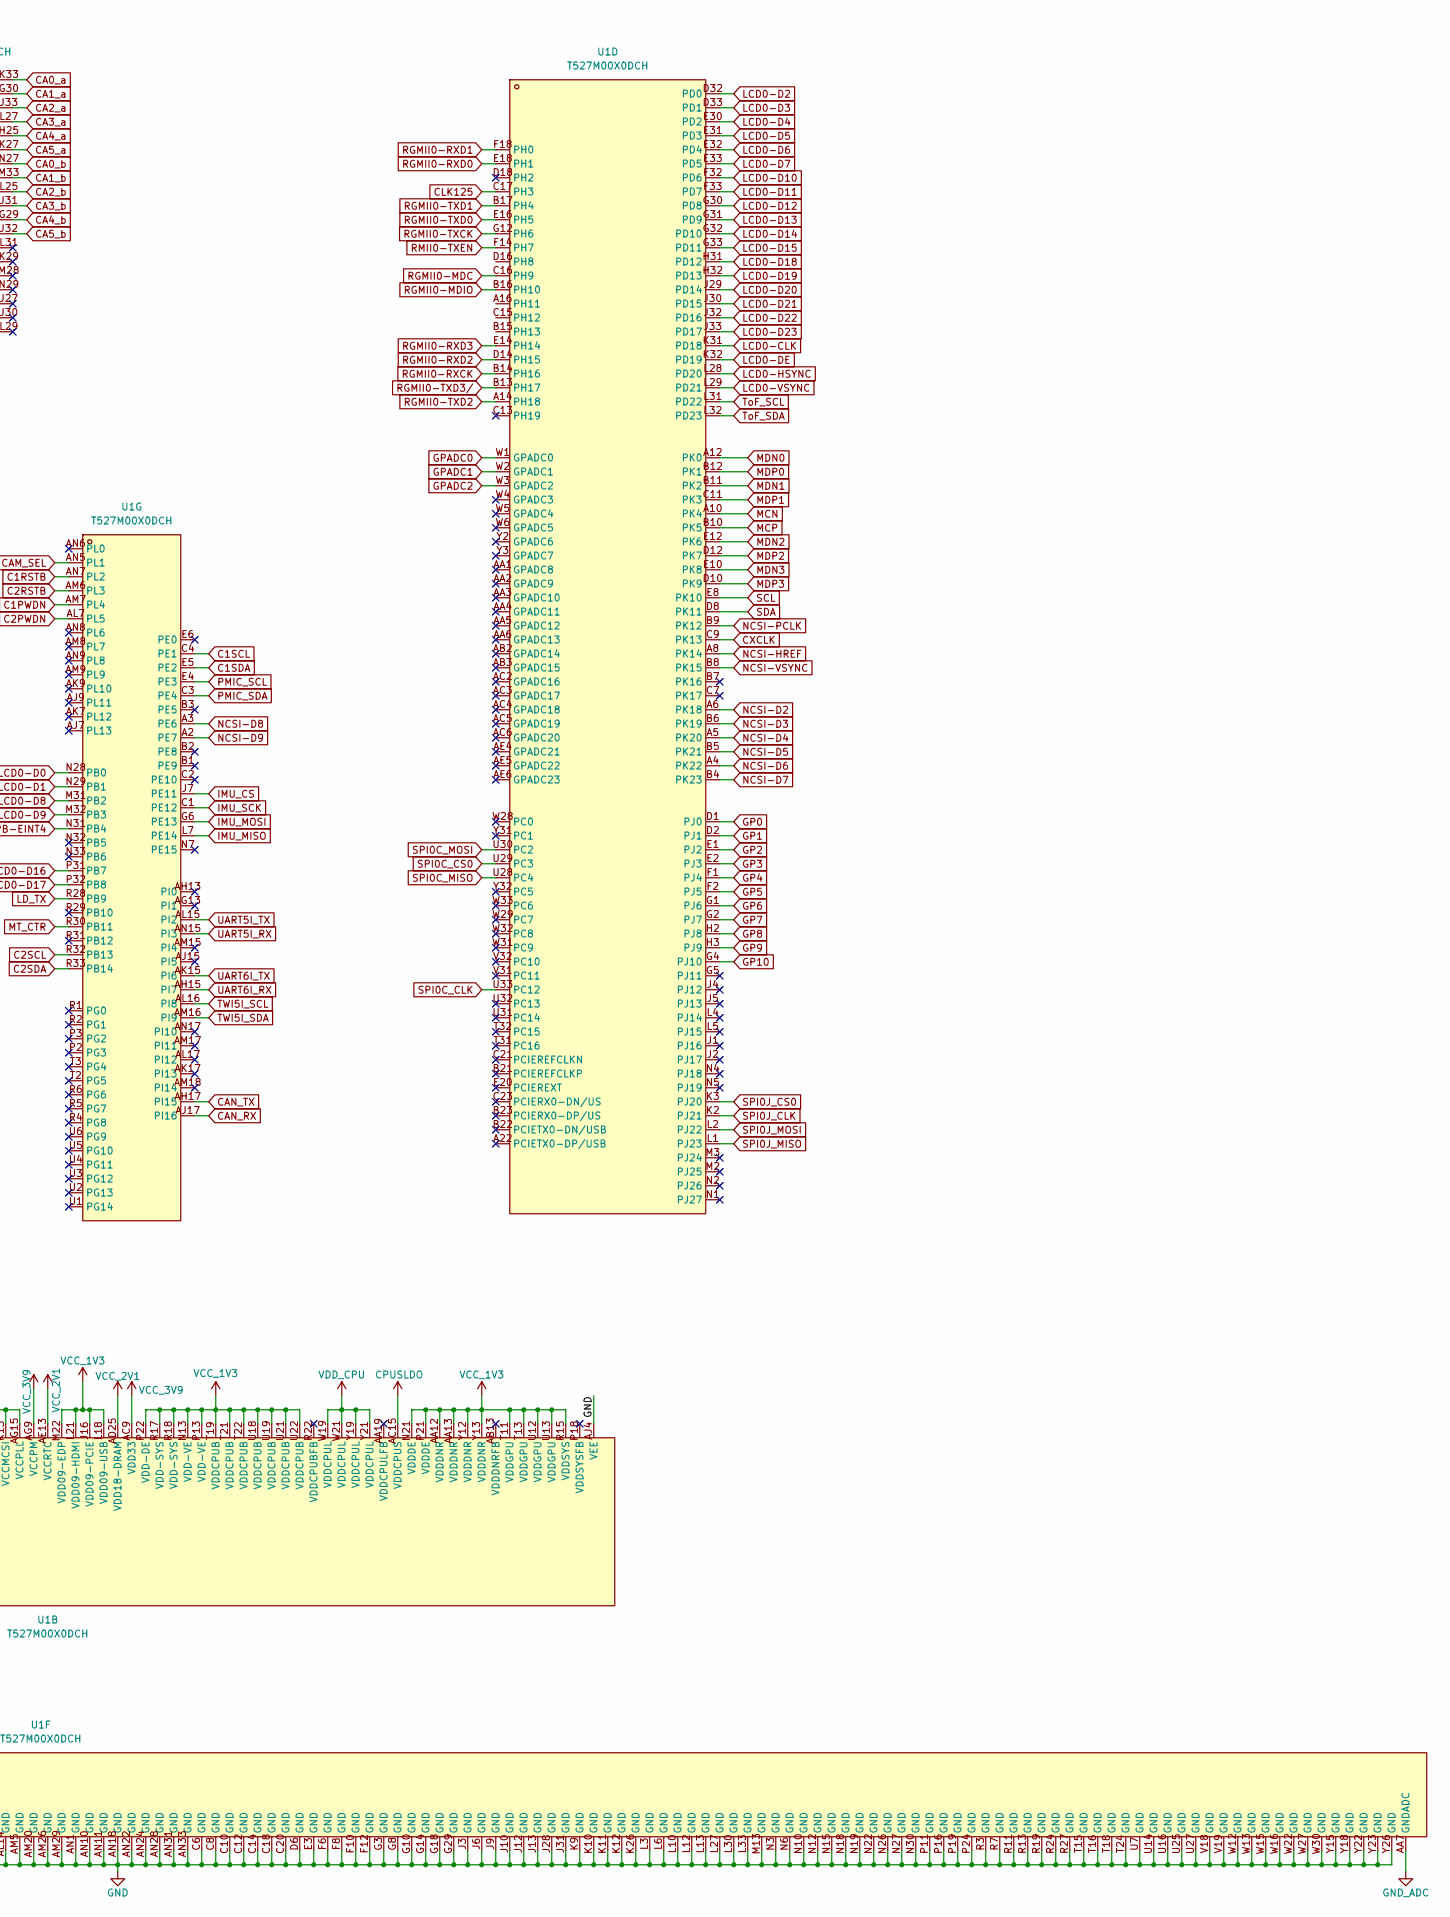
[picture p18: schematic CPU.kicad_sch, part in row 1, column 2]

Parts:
C44, C45: 12pF; C_0402_1005Metric
R20: 10K; R_0402_1005Metric
R21, R22, R23: 2K; R_0402_1005Metric
U1: T527M00X0DCH; BGA-664_L17.0-W17.0_T527; MPN T527M00X0DCH; LCSC Part C28310420
Y2: 24MHz; Crystal_SMD_3225-4Pin_3.2x2.5mm

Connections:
/CPU/DXIN: C44.1, U1.AM13 (DXIN), Y2.1
/CPU/DXOUT: C45.1, U1.AN13 (DXOUT), Y2.3
/CPU/USB0-REXT: R21.1, U1.G22 (USB0-REXT)
/CPU/USB1-REXT: R22.1, U1.G24 (USB1-REXT)
/CPU/USB2-REXT: R23.1, U1.G20 (USB2-REXT)
C1PWDN: U1.AM7 (PL4); also elsewhere on the board
C1RSTB: U1.AN7 (PL2); also elsewhere on the board
C1SCL: U1.C4 (PE1); also elsewhere on the board
C1SDA: U1.E5 (PE2); also elsewhere on the board
C2PWDN: U1.AL7 (PL5); also elsewhere on the board
C2RSTB: U1.AM6 (PL3); also elsewhere on the board
C2SCL: U1.R32 (PB13); also elsewhere on the board
C2SDA: U1.R33 (PB14); also elsewhere on the board
CA0_a: U1.AK33 (SA0); also elsewhere on the board
CA0_b: U1.AN27 (SA6); also elsewhere on the board
CA1_a: U1.AG30 (SA1); also elsewhere on the board
CA1_b: U1.AM33 (SA7); also elsewhere on the board
CA2_a: U1.AJ33 (SA2); also elsewhere on the board
CA2_b: U1.AL25 (SA8); also elsewhere on the board
CA3_a: U1.AL27 (SA3); also elsewhere on the board
CA3_b: U1.AJ31 (SA9); also elsewhere on the board
CA4_a: U1.AH25 (SA4); also elsewhere on the board
CA4_b: U1.AG29 (SA10); also elsewhere on the board
CA5_a: U1.AK27 (SA5); also elsewhere on the board
CA5_b: U1.AJ32 (SA11); also elsewhere on the board
CAM_SEL: U1.AN5 (PL1); also elsewhere on the board
CAN_RX: U1.AJ17 (PI16); also elsewhere on the board
CAN_TX: U1.AH17 (PI15); also elsewhere on the board
CEK_a: U1.AM31 (SCKE0); also elsewhere on the board
CK_c_a: U1.AN30 (SCKN); also elsewhere on the board
CK_t_a: U1.AM30 (SCKP); also elsewhere on the board
CLK125: U1.C17 (PH3); also elsewhere on the board
CPUSLDO: U1.AC15 (VDDCPUS); also elsewhere on the board
CS_a: U1.AN32 (SCS0); also elsewhere on the board
CS_b: U1.AM32 (SCS1); also elsewhere on the board
CXCLK: U1.C9 (PK13); also elsewhere on the board
DMI0_A: U1.AE33 (SDQM0); also elsewhere on the board
DMI0_B: U1.AM24 (SDQM2); also elsewhere on the board
DMI1_A: U1.AC32 (SDQM1); also elsewhere on the board
DMI1_B: U1.AN20 (SDQM3); also elsewhere on the board
DQ0_A: U1.AE28 (SDQ0); also elsewhere on the board
DQ0_B: U1.AM25 (SDQ16); also elsewhere on the board
DQ1_A: U1.AE27 (SDQ1); also elsewhere on the board
DQ1_B: U1.AN25 (SDQ17); also elsewhere on the board
DQ2_A: U1.AG32 (SDQ2); also elsewhere on the board
DQ2_B: U1.AH23 (SDQ18); also elsewhere on the board
DQ3_A: U1.AH33 (SDQ3); also elsewhere on the board
DQ3_B: U1.AK23 (SDQ19); also elsewhere on the board
DQ4_A: U1.AE30 (SDQ4); also elsewhere on the board
DQ4_B: U1.AL23 (SDQ20); also elsewhere on the board
DQ5_A: U1.AD32 (SDQ5); also elsewhere on the board
DQ5_B: U1.AM22 (SDQ21); also elsewhere on the board
DQ6_A: U1.AE31 (SDQ6); also elsewhere on the board
DQ6_B: U1.AN21 (SDQ22); also elsewhere on the board
DQ7_A: U1.AD33 (SDQ7); also elsewhere on the board
DQ7_B: U1.AG21 (SDQ23); also elsewhere on the board
DQ8_A: U1.AC27 (SDQ8); also elsewhere on the board
DQ8_B: U1.AG19 (SDQ24); also elsewhere on the board
DQ9_A: U1.AC28 (SDQ9); also elsewhere on the board
DQ9_B: U1.AH19 (SDQ25); also elsewhere on the board
DQ10_A: U1.AC30 (SDQ10); also elsewhere on the board
DQ10_B: U1.AK19 (SDQ26); also elsewhere on the board
DQ11_A: U1.AC31 (SDQ11); also elsewhere on the board
DQ11_B: U1.AL19 (SDQ27); also elsewhere on the board
DQ12_A: U1.AA33 (SDQ12); also elsewhere on the board
DQ12_B: U1.AM21 (SDQ28); also elsewhere on the board
DQ13_A: U1.AA31 (SDQ13); also elsewhere on the board
DQ13_B: U1.AL21 (SDQ29); also elsewhere on the board
DQ14_A: U1.AA28 (SDQ14); also elsewhere on the board
DQ14_B: U1.AK21 (SDQ30); also elsewhere on the board
DQ15_A: U1.AA27 (SDQ15); also elsewhere on the board
DQ15_B: U1.AH21 (SDQ31); also elsewhere on the board
DQS0_c_a: U1.AF33 (SDQS0N); also elsewhere on the board
DQS0_t_a: U1.AF32 (SDQS0P); also elsewhere on the board
DQS1_c_a: U1.AB33 (SDQS1N); also elsewhere on the board
DQS1_t_a: U1.AB32 (SDQS1P); also elsewhere on the board
DQS2_c_a: U1.AN23 (SDQS2N)
DQS2_t_a: U1.AM23 (SDQS2P)
DQS3_c_a: U1.AN19 (SDQS3N)
DQS3_t_a: U1.AM19 (SDQS3P)
GND: C44.2, C45.2, R21.2, R22.2, R23.2, U1.A1 (GND), U1.AA15 (GND), U1.AA16 (GND), U1.AA18 (GND), U1.AA21 (GND), U1.AA22 (GND), U1.AA26 (GND), U1.AA30 (GND), U1.AA32 (GND), U1.AB10 (GND), U1.AB11 (GND), U1.AB12 (GND), U1.AB14 (GND), U1.AB15 (GND), U1.AB17 (GND), U1.AC1 (GND), U1.AC26 (GND), U1.AC29 (GND), U1.AC33 (GND), U1.AD9 (GND), U1.AD11 (GND), U1.AD13 (GND), U1.AD14 (GND), U1.AD20 (GND), U1.AD21 (GND), U1.AD22 (GND), U1.AE9 (GND), U1.AE12 (GND), U1.AE14 (GND), U1.AE18 (GND), U1.AE19 (GND), U1.AE20 (GND), U1.AE21 (GND), U1.AE22 (GND), U1.AE23 (GND), U1.AE24 (GND), U1.AE25 (GND), U1.AE26 (GND), U1.AE29 (GND), U1.AE32 (GND), U1.AG3 (GND), U1.AG6 (GND), U1.AG7 (GND), U1.AG11 (GND), U1.AG25 (GND), U1.AG28 (GND), U1.AG31 (GND), U1.AG33 (GND), U1.AH7 (GND), U1.AH9 (GND), U1.AH27 (GND), U1.AH32 (GND), U1.AJ4 (VEE), U1.AJ13 (GND), U1.AJ19 (GND), U1.AJ21 (GND), U1.AJ23 (GND), U1.AK2 (CPVEE), U1.AK5 (GND), U1.AK11 (GND), U1.AK32 (GND), U1.AL3 (GND), U1.AL9 (GND), U1.AL12 (GND), U1.AL13 (GND), U1.AL14 (GND), U1.AM5 (GND), U1.AM20 (GND), U1.AM26 (GND), U1.AM29 (GND), U1.AN1 (GND), U1.AN10 (GND), U1.AN11 (GND), U1.AN18 (GND), U1.AN22 (GND), U1.AN24 (GND), U1.AN28 (GND), U1.AN31 (GND), U1.AN33 (GND), U1.C6 (GND), U1.C8 (GND), U1.C10 (GND), U1.C12 (GND), U1.C14 (GND), U1.C18 (GND), U1.C20 (GND), U1.D6 (GND), U1.E3 (GND), U1.F6 (GND), U1.F8 (GND), U1.F10 (GND), U1.F12 (GND), U1.G3 (GND), U1.G8 (GND), U1.G10 (GND), U1.G14 (GND), U1.G18 (GND), U1.G29 (GND), U1.J3 (GND), U1.J6 (GND), U1.J9 (GND), U1.J10 (GND), U1.J12 (GND), U1.J13 (GND), U1.J28 (GND), U1.J31 (GND), U1.K9 (GND), U1.K10 (GND), U1.K11 (GND), U1.K12 (GND), U1.K26 (GND), U1.L3 (GND), U1.L6 (GND), U1.L10 (GND), U1.L12 (GND), U1.L13 (GND), U1.L27 (GND), U1.L30 (GND), U1.L33 (GND), U1.M13 (GND), U1.N3 (GND), U1.N6 (GND), U1.N10 (GND), U1.N12 (GND), U1.N15 (GND), U1.N18 (GND), U1.N19 (GND), U1.N22 (GND), U1.N26 (GND), U1.N27 (GND), U1.N30 (GND), U1.P11 (GND), U1.P16 (GND), U1.P19 (GND), U1.P24 (GND), U1.R3 (GND), U1.R7 (GND), U1.R11 (GND), U1.R13 (GND), U1.R19 (GND), U1.R24 (GND), U1.R27 (GND), U1.T15 (GND), U1.T16 (GND), U1.T18 (GND), U1.T24 (GND), U1.U7 (GND), U1.U14 (GND), U1.U16 (GND), U1.U25 (GND), U1.U27 (GND), U1.V18 (GND), U1.V19 (GND), U1.W12 (GND), U1.W13 (GND), U1.W15 (GND), U1.W16 (GND), U1.W22 (GND), U1.W27 (GND), U1.W30 (GND), U1.Y15 (GND), U1.Y18 (GND), U1.Y22 (GND), U1.Y23 (GND), U1.Y26 (GND), Y2.2 (G), Y2.4 (G); also elsewhere on the board
GNDA: U1.A32 (AVSS), U1.A33 (AVSS), U1.AE3 (AGND), U1.C22 (AVSS), U1.C24 (AVSS), U1.C26 (AVSS), U1.C28 (AVSS), U1.C30 (AVSS), U1.C31 (AVSS), U1.E29 (AVSS), U1.F22 (AVSS), U1.F24 (AVSS), U1.G26 (AVSS), U1.G28 (AVSS), U1.H24 (AVSS), U1.J17 (AVSS), U1.J21 (AVSS), U1.J22 (AVSS), U1.J23 (AVSS), U1.J26 (AVSS), U1.K15 (AVSS), U1.K16 (AVSS), U1.K21 (AVSS), U1.K22 (AVSS), U1.K24 (AVSS), U1.K25 (AVSS), U1.L16 (AVSS), U1.L19 (AVSS), U1.L24 (AVSS), U1.M16 (AVSS), U1.M18 (AVSS), U1.M19 (AVSS)
GND_ADC: U1.AA7 (GNDADC)
GP0: U1.D1 (PJ0); also elsewhere on the board
GP1: U1.D2 (PJ1); also elsewhere on the board
GP2: U1.E1 (PJ2); also elsewhere on the board
GP3: U1.E2 (PJ3); also elsewhere on the board
GP4: U1.F1 (PJ4); also elsewhere on the board
GP5: U1.F2 (PJ5); also elsewhere on the board
GP6: U1.G1 (PJ6); also elsewhere on the board
GP7: U1.G2 (PJ7); also elsewhere on the board
GP8: U1.H2 (PJ8); also elsewhere on the board
GP9: U1.H3 (PJ9); also elsewhere on the board
GP10: U1.G4 (PJ10); also elsewhere on the board
GPADC0: U1.W1 (GPADC0); also elsewhere on the board
GPADC1: U1.W2 (GPADC1); also elsewhere on the board
GPADC2: U1.W3 (GPADC2); also elsewhere on the board
HBIAS: U1.AL1 (HBIAS)
HCEC: U1.E28 (HCEC); also elsewhere on the board
HHPD: U1.D28 (HHPD); also elsewhere on the board
HPOUTFB: U1.AM1 (HPOUTFB); also elsewhere on the board
HPOUTL: U1.AL2 (HPOUTL); also elsewhere on the board
HPOUTR: U1.AM2 (HPOUTR); also elsewhere on the board
HSCL: U1.D26 (HSCL); also elsewhere on the board
HSDA: U1.E26 (HSDA); also elsewhere on the board
HTX0N: U1.C27 (HTX0N); also elsewhere on the board
HTX0P: U1.B27 (HTX0P); also elsewhere on the board
HTX1N: U1.B26 (HTX1N); also elsewhere on the board
HTX1P: U1.A26 (HTX1P); also elsewhere on the board
HTX2N: U1.C25 (HTX2N); also elsewhere on the board
HTX2P: U1.B25 (HTX2P); also elsewhere on the board
HTXCN: U1.B28 (HTXCN); also elsewhere on the board
HTXCP: U1.A28 (HTXCP); also elsewhere on the board
IMU_CS: U1.J7 (PE11); also elsewhere on the board
IMU_MISO: U1.L7 (PE14); also elsewhere on the board
IMU_MOSI: U1.G6 (PE13); also elsewhere on the board
IMU_SCK: U1.C1 (PE12); also elsewhere on the board
LCD0-CLK: U1.K31 (PD18); also elsewhere on the board
LCD0-D0: U1.N28 (PB0); also elsewhere on the board
LCD0-D1: U1.N29 (PB1); also elsewhere on the board
LCD0-D2: U1.D32 (PD0); also elsewhere on the board
LCD0-D3: U1.D33 (PD1); also elsewhere on the board
LCD0-D4: U1.E30 (PD2); also elsewhere on the board
LCD0-D5: U1.E31 (PD3); also elsewhere on the board
LCD0-D6: U1.E32 (PD4); also elsewhere on the board
LCD0-D7: U1.E33 (PD5); also elsewhere on the board
LCD0-D8: U1.M31 (PB2); also elsewhere on the board
LCD0-D9: U1.M32 (PB3); also elsewhere on the board
LCD0-D10: U1.F32 (PD6); also elsewhere on the board
LCD0-D11: U1.F33 (PD7); also elsewhere on the board
LCD0-D12: U1.G30 (PD8); also elsewhere on the board
LCD0-D13: U1.G31 (PD9); also elsewhere on the board
LCD0-D14: U1.G32 (PD10); also elsewhere on the board
LCD0-D15: U1.G33 (PD11); also elsewhere on the board
LCD0-D16: U1.P31 (PB7); also elsewhere on the board
LCD0-D17: U1.P32 (PB8); also elsewhere on the board
LCD0-D18: U1.H31 (PD12); also elsewhere on the board
LCD0-D19: U1.H32 (PD13); also elsewhere on the board
LCD0-D20: U1.J29 (PD14); also elsewhere on the board
LCD0-D21: U1.J30 (PD15); also elsewhere on the board
LCD0-D22: U1.J32 (PD16); also elsewhere on the board
LCD0-D23: U1.J33 (PD17); also elsewhere on the board
LCD0-DE: U1.K32 (PD19); also elsewhere on the board
LCD0-HSYNC: U1.L28 (PD20); also elsewhere on the board
LCD0-VSYNC: U1.L29 (PD21); also elsewhere on the board
LD_TX: U1.R28 (PB9); also elsewhere on the board
MBIAS: U1.AK1 (MBIAS); also elsewhere on the board
MCN: U1.A10 (PK4)
MCP: U1.B10 (PK5)
MDN0: U1.A12 (PK0)
MDN1: U1.B11 (PK2)
MDN2: U1.E12 (PK6)
MDN3: U1.E10 (PK8)
MDP0: U1.B12 (PK1)
MDP1: U1.C11 (PK3)
MDP2: U1.D12 (PK7)
MDP3: U1.D10 (PK9)
MICIN1N: U1.AD1 (MICIN1N); also elsewhere on the board
MICIN1P: U1.AD2 (MICIN1P); also elsewhere on the board
MT_CTR: U1.R30 (PB11); also elsewhere on the board
NCSI-D2: U1.A6 (PK18); also elsewhere on the board
NCSI-D3: U1.B6 (PK19); also elsewhere on the board
NCSI-D4: U1.A5 (PK20); also elsewhere on the board
NCSI-D5: U1.B5 (PK21); also elsewhere on the board
NCSI-D6: U1.A4 (PK22); also elsewhere on the board
NCSI-D7: U1.B4 (PK23); also elsewhere on the board
NCSI-D8: U1.A3 (PE6); also elsewhere on the board
NCSI-D9: U1.A2 (PE7); also elsewhere on the board
NCSI-HREF: U1.A8 (PK14); also elsewhere on the board
NCSI-PCLK: U1.B9 (PK12); also elsewhere on the board
NCSI-VSYNC: U1.B8 (PK15); also elsewhere on the board
ODT_CA_a: U1.AL32 (SODT0); also elsewhere on the board
ODT_CA_b: U1.AL33 (SODT1); also elsewhere on the board
PB-EINT4: U1.N31 (PB4); also elsewhere on the board
PMIC_POK: R20.2, U1.AJ11 (RESET); also elsewhere on the board
PMIC_SCL: U1.E4 (PE3); also elsewhere on the board
PMIC_SDA: U1.C3 (PE4); also elsewhere on the board
RESET_n: U1.AG23 (SRST); also elsewhere on the board
RGMII0-MDC: U1.C16 (PH9); also elsewhere on the board
RGMII0-MDIO: U1.B16 (PH10); also elsewhere on the board
RGMII0-RXCK: U1.B14 (PH16); also elsewhere on the board
RGMII0-RXD0: U1.E18 (PH1); also elsewhere on the board
RGMII0-RXD1: U1.F18 (PH0); also elsewhere on the board
RGMII0-RXD2: U1.D14 (PH15); also elsewhere on the board
RGMII0-RXD3: U1.E14 (PH14); also elsewhere on the board
RGMII0-TXCK: U1.G12 (PH6); also elsewhere on the board
RGMII0-TXD0: U1.E16 (PH5); also elsewhere on the board
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

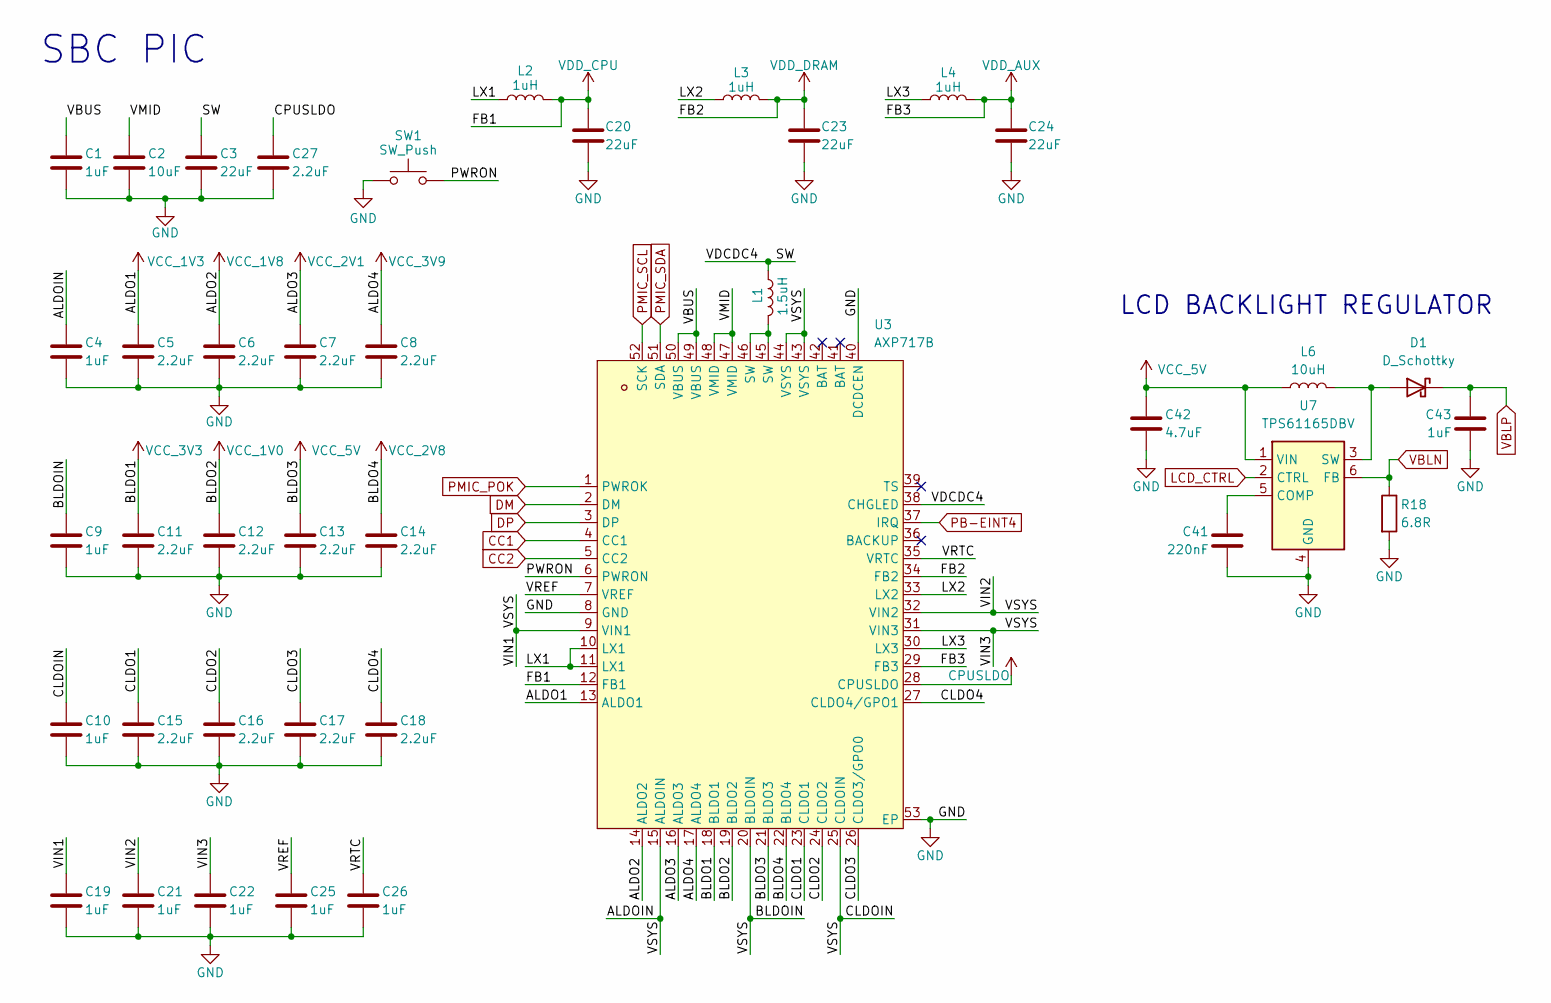
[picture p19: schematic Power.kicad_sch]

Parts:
C1, C4, C9, C10, C19, C21, C22, C25, C26, C43: 1uF; C_0805_2012Metric
C2: 10uF; C_0805_2012Metric
C3, C20, C23, C24: 22uF; C_0805_2012Metric
C5, C6, C7, C8, C11, C12, C13, C14, C15, C16, C17, C18, C27: 2.2uF; C_0805_2012Metric
C41: 220nF; C_0402_1005Metric
C42: 4.7uF; C_0805_2012Metric
D1: D_Schottky; D_SOD-123
L1: 1.5uH; L_Cenker_CKCS3015
L2, L3, L4: 1uH; L_Cenker_CKCS3015
L6: 10uH; L_Cenker_CKCS3012
R18: 6.8R; R_0402_1005Metric
SW1: SW_Push; SW_Push_SPST_NO_Alps_SKRK
U3: AXP717B; QFN-52_L6.0-W6.0-P0.40-TL-EP4.5; MPN AXP717B; LCSC Part C45360051
U7: TPS61165DBV; SOT-23-6

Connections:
/Power/ALDOIN: C4.1, C9.1, C10.1, C19.1, C21.1, C22.1, U3.9 (VIN1), U3.15 (ALDOIN), U3.20 (BLDOIN), U3.25 (CLDOIN), U3.31 (VIN3), U3.32 (VIN2), U3.43 (VSYS), U3.44 (VSYS)
/Power/CLDO1: C15.1, U3.23 (CLDO1)
/Power/CLDO2: C16.1, U3.24 (CLDO2)
/Power/CLDO3: C17.1, U3.26 (CLDO3/GPO0)
/Power/CLDO4: C18.1, U3.27 (CLDO4/GPO1)
/Power/LX1: L2.1, U3.10 (LX1), U3.11 (LX1)
/Power/LX2: L3.1, U3.33 (LX2)
/Power/LX3: L4.1, U3.30 (LX3)
/Power/PWRON: SW1.1, U3.6 (PWRON)
/Power/SW: C3.1, L1.1, U3.38 (CHGLED)
/Power/VBUS: C1.1, U3.49 (VBUS), U3.50 (VBUS)
/Power/VMID: C2.1, U3.47 (VMID), U3.48 (VMID)
/Power/VREF: C25.1, U3.7 (VREF)
/Power/VRTC: C26.1, U3.35 (VRTC)
CC1: U3.4 (CC1)
CC2: U3.5 (CC2)
CPUSLDO: C27.1, U3.28 (CPUSLDO); also elsewhere on the board
DM: U3.2 (DM)
DP: U3.3 (DP)
GND: C1.2, C2.2, C3.2, C4.2, C5.2, C6.2, C7.2, C8.2, C9.2, C10.2, C11.2, C12.2, C13.2, C14.2, C15.2, C16.2, C17.2, C18.2, C19.2, C20.2, C21.2, C22.2, C23.2, C24.2, C25.2, C26.2, C27.2, C41.2, C42.2, C43.2, R18.2, SW1.2, U3.8 (GND), U3.40 (DCDCEN), U3.53 (EP), U7.4 (GND); also elsewhere on the board
LCD_CTRL: U7.2 (CTRL)
unnamed: D1.2 (A), L6.2, U7.3 (SW)
unnamed: L1.2, U3.45 (SW), U3.46 (SW)
unnamed: C41.1, U7.5 (COMP)
PB-EINT4: U3.37 (IRQ); also elsewhere on the board
PMIC_POK: U3.1 (PWROK); also elsewhere on the board
PMIC_SCL: U3.52 (SCK); also elsewhere on the board
PMIC_SDA: U3.51 (SDA); also elsewhere on the board
VBLN: R18.1, U7.6 (FB); also elsewhere on the board
VBLP: C43.1, D1.1 (K); also elsewhere on the board
VCC_1V0: C12.1, U3.19 (BLDO2); also elsewhere on the board
VCC_1V3: C5.1, U3.13 (ALDO1); also elsewhere on the board
VCC_1V8: C6.1, U3.14 (ALDO2); also elsewhere on the board
VCC_2V1: C7.1, U3.16 (ALDO3); also elsewhere on the board
VCC_2V8: C14.1, U3.22 (BLDO4); also elsewhere on the board
VCC_3V3: C11.1, U3.18 (BLDO1); also elsewhere on the board
VCC_3V9: C8.1, U3.17 (ALDO4); also elsewhere on the board
VCC_5V: C13.1, C42.1, L6.1, U3.21 (BLDO3), U7.1 (VIN); also elsewhere on the board
VDD_AUX: C24.1, L4.2, U3.29 (FB3)
VDD_CPU: C20.1, L2.2, U3.12 (FB1); also elsewhere on the board
VDD_DRAM: C23.1, L3.2, U3.34 (FB2); also elsewhere on the board

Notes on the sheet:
SBC PIC
LCD BACKLIGHT REGULATOR

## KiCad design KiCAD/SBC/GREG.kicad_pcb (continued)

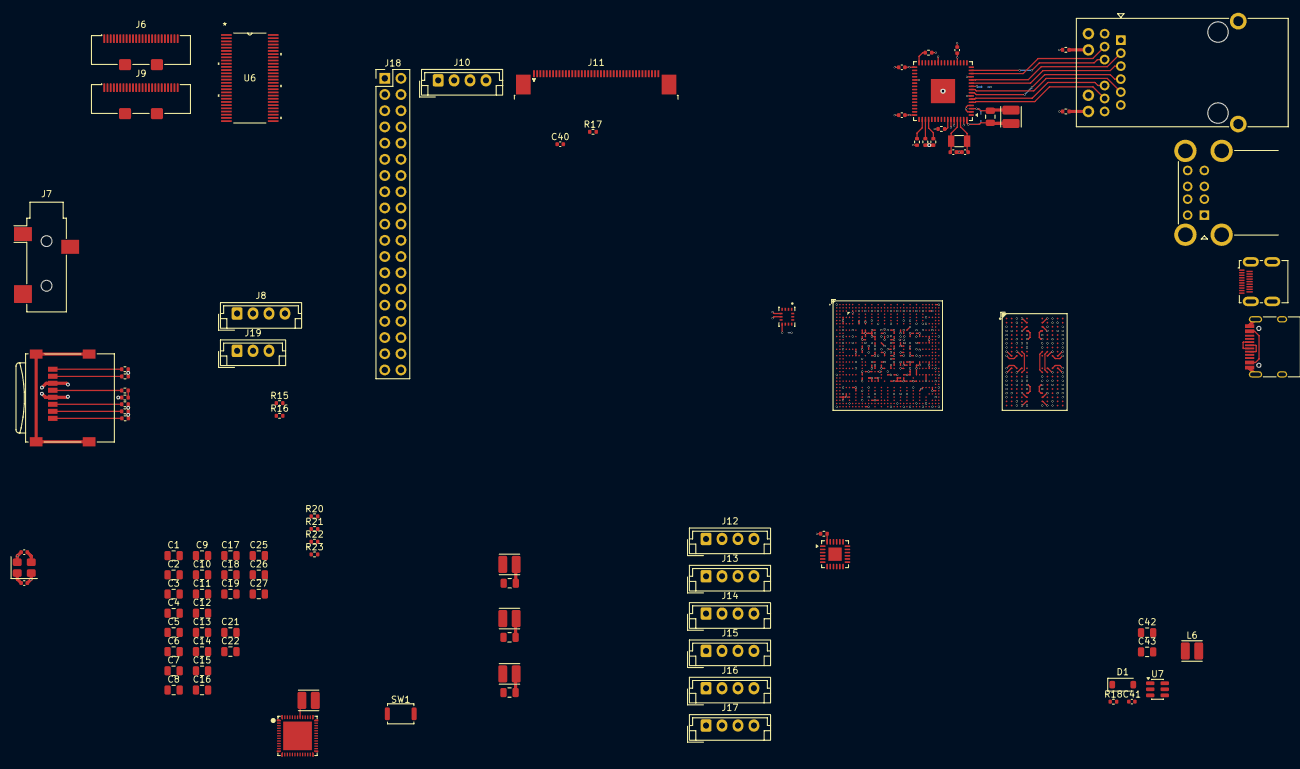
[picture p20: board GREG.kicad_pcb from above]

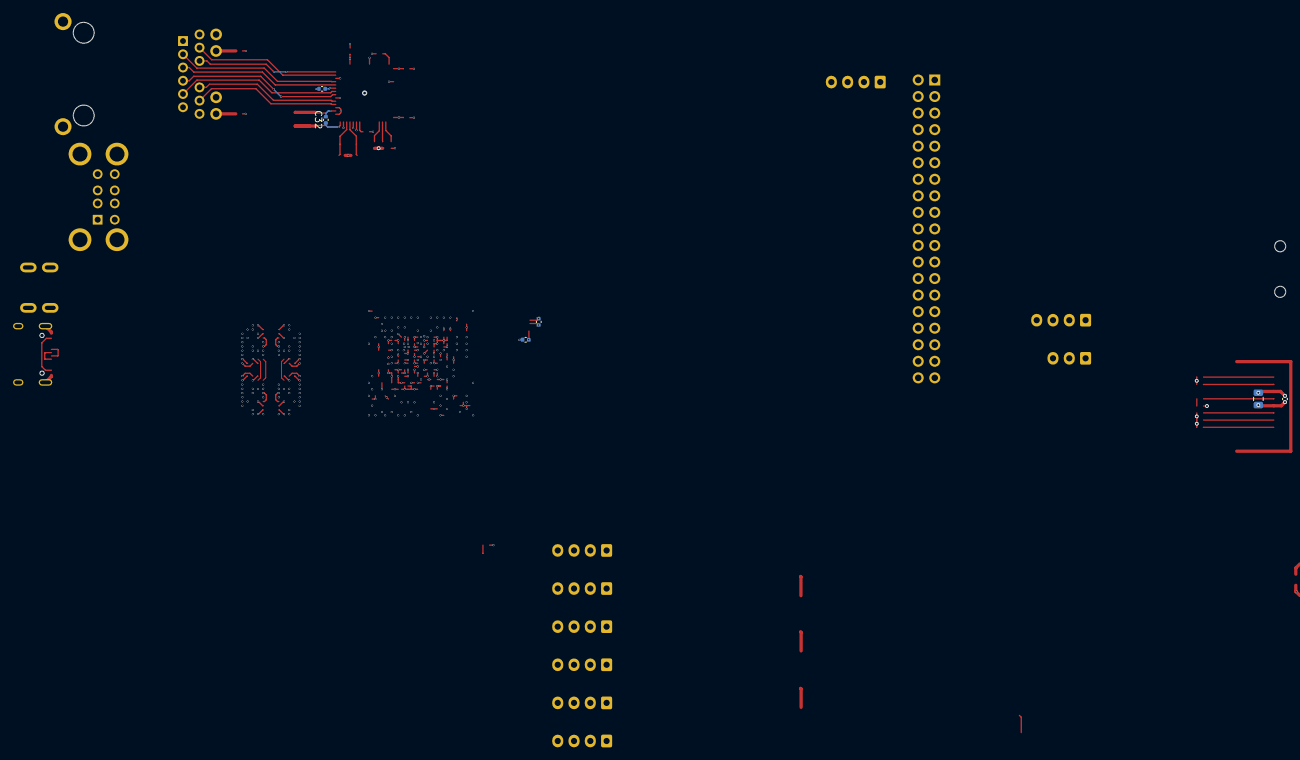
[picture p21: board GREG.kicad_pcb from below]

Board: 10 copper layers, 105 parts (6 on the bottom side), 293 nets.

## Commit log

2026-09-27 Add data for schematics week
    [CPU.kicad_sch, Connectivity.kicad_sch, GREG-MTRDRV.kicad_pcb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]
2026-09-27 Add CAD repository link to README
    Added CAD repository link for the Orion Rover project.
2026-10-04 Add journal and update readme
    [Connectivity.kicad_sch, GREG-MTRDRV.kicad_pcb, GREG-MTRDRV.kicad_sch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]
